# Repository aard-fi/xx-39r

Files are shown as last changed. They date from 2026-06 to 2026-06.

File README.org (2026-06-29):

* XX-39R                                                              :TOC_4:
- [[#overview][Overview]]
- [[#licensing][Licensing]]
- [[#quick-springtide-40-conversion-guide][Quick springtide 40 conversion guide]]
- [[#xx-39r265c27-3-the-original-hardware][XX-39R/265C27-3, the original hardware]]
- [[#elrs-replacement][ELRS replacement]]
  - [[#firmware][Firmware]]
    - [[#variants][Variants]]
    - [[#building][Building]]
    - [[#flashing][Flashing]]
    - [[#fuses][Fuses]]
  - [[#verify-functionality][Verify functionality]]

* Overview

This repository is for documenting a pretty bad receiver and motor driver board for a RC boat labeled =XX-39R= and =265C27-3=, as well as a replacement for it. The board can be found in models like "Revell Spring Tide 40", but has no place in a toy from this decade (or the last) - the reception is absolutely horrible, and there are better options available nowadays.

Read the sections below for a more detailed board description, as well as our "absolute overkill" option for replacing it with something better. While the replacement board is designed as drop in replacement for this model it has been designed with reusability for other small models in mind as well - which also would be listed here.

* Licensing

All source code is licensed under [[https://www.google.com/url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][GPLv2]]. PCB related KiCad files are licensed under [[https://creativecommons.org/licenses/by-nc-sa/4.0/][CC BY-NC-SA 4.0]].

* Quick springtide 40 conversion guide

Open all the screws on the boat, and open the small electronics box. Submerge the board into isopropyl alcohol for roughly 24 hours - and while wet, remove the plugs. They should come out relatively easy now.
Remove the antenna wire from the hole, and remove the board.

Assuming you have a board populated with SMD components, now you'll need to

- solder JST-PH 2.0 headers into J1, J2, J3 and J4
- solder a jumper into or bridge J13
- solder a pin header (male or female - female might be more comfortabe with some programmers) into J5
- solder a pin header into J6. Recommendation would be angled male, and female on the ELRS receiver

The layout is the same as the original - the JST headers and the ELRS module most go to the underside of the board (inside the silk screen markings). For the programmer an angled header has space on top as well, and can allow for easier reflashing.

Next you can connect your UPDI programmer to the board and the PC, download the latest firmware archive from the release page, unzip, and run =flash.sh= (Linux/MacOS) or =flash.ps1= (Windows), and follow the instructions. Select the 10MHz springtide firmware, and decide if you want the water sensor.

Plug in the ELRS receiver and he motor, battery and sensor wires. Do a quick functionality test with batteries and a remote and then put everything together.

* XX-39R/265C27-3, the original hardware

The board is built around the [[https://www.talkingelectronics.com/projects/27MHz%20Transmitters/imagesP2/RX2Bdatasheet-5function.pdf][TX-2B/RX-2B]] transmitter/receiver combo. The problem here is less with that chip, but more that it can be used with the cheapest possible receiver circuit (in this case, tuned to 40MHz), which does not behave well in the real world.

The remote control has 4 buttons: binary inputs for reverse/forward for each of the motors. So no speed control, and steering by only using one motor (or reversing the other, for tight turns).

The motor controller is a [[https://www.lcsc.com/product-detail/Motor-Driver-ICs_Mixic-MX1616H_C5119044.html][MX1616H]] - which is a reasonable choice for a boat powered by 4.5V.

Additionally, there's a protection circuit to detect a current between the two motors to avoid activation outside of the water.

The schematic in the =pcb= directory currently should be mostly complete, with the exception of the receiver circuit.

* ELRS replacement

For our replacement we're relying on an ELRS receiver. While absolute overkill for such a boat it'll allow a nice upgrade path to larger models later on. The hardware can support any small receivers using a serial protocol - so if you have spare older receivers around it can be adapted to use that instead. We don't want to touch other parts of the boat - so while we could use 14500 cells instead of AA we'd have to lower the voltage to make sure we don't burn out the motors.

The easier way is to just stick with the 4.5V architecture, and only boost voltage for the ELRS receiver.

We can reuse the motor controller as well as the protection circuit - but as we want to support the cheapest possible ELRS remotes we can't rely on track mixing in the remote, and therefore need a cheap microcontroller to interface between the receiver and the motor controller. We can use an AtTiny414 for that - it'll work over the complete voltage range we can expect this to operate at. An AtTiny412 would be possible - but we'd have to reuse the UPDI pin.

All unused pins on the MCU are lead out, as well as some spare footprints for VCC and GND pins. The complete table of pin headers is:

| Reference | Description     | Comment                                                                |
|-----------+-----------------+------------------------------------------------------------------------|
| J1        | Sense           |                                                                        |
| J2        | Battery         | Designed for 4.5V, but can take up to 5.5V                             |
| J3        | Port motor      |                                                                        |
| J4        | Starboard motor |                                                                        |
| J5        | UPDI            |                                                                        |
| J6        | Receiver        | Designed for ELRS, but can be used otherwise as well. See pinout below |
| J7        | PA6             |                                                                        |
| J8        | PA1             |                                                                        |
| J9        | PA3             |                                                                        |
| J10       | PA2             |                                                                        |
| J11       | Spare VCC       |                                                                        |
| J12       | Spare VCC       |                                                                        |
| J13       | Receiver VCC    | Bridge to use the on board booster, or connect your own                |
| J14       | Spare GND       |                                                                        |
| J15       | Spare GND       |                                                                        |
| J16       | Spare GND       |                                                                        |

The header for the (ELRS) receiver (=J6=) has the following pinout:

| Pin | ELRS | MCU           | Pin |
|-----+------+---------------+-----|
|   1 | GND  | GND           |     |
|   2 | VCC  | -             |     |
|   3 | TX   | PB3, UART1 RX |   6 |
|   4 | RX   | PB2, UART1 TX |   7 |

Any receiver using a serial protocol (like FlySky AFHDS) could be used, though the firmware here only supports ELRS.

The motor headers are connected as follows:

|           |          |       |      |     |          |
|-----------+----------+-------+------+-----+----------|
| Port      | J3 pin 1 | OUTA1 | INA1 | PA4 | =M1_FWD=   |
|           | J3 pin 2 | OUTB1 | INB1 | PA5 | =M1_REV=   |
| Starboard | J4 pin 1 | OUTA2 | INA2 | PB0 | =M2_FWD=   |
|           | J4 pin 2 | OUTB2 | INB2 | PB1 | =M2_REV= |

** Firmware

This is build with =common.hpp= containing code for all bigger features, and the individual firmware variants can use that to build model specific variants in less than 50 lines of code.

Common features are

- direction-change dead time (~50–80 ms coast) prevents regenerative voltage spikes
- rate limiting (±25 PWM per packet accel) makes it both more controllable (kid friendly) and prevents hardware destroying voltage spikes
- low-voltage cutoff (2.8 V) can stop motors before brownout
- custom CRSF parser, somewhat resilient: we try to re-sync if we read too much garbage, and stop the motors if we can't get it back
- water sensor readings, in safety mode (motors directly shut off) or just reading for extra data
- battery voltage readings
- support for different CPU speeds: 5, 10, 16 and 20MHz
- simple RX and TX buffering for UART communications
- optional "kickstart" support: on slow speeds do occasional kicks to get the motor started

*** Variants

We can build variants with extra features from base sources, with the filename containing markers to show what it is:

- *-ks* — Motor kickstart enabled (helps low-speed startup)
- *-ws* — Water safety sensor enabled. Recommended for kids - motors stop when the boat is removed from the water.
- *-5m*, *-10m*, *-16m* — CPU frequency variants (default = 20 MHz)

All release builds have frequency markers, only manual builds for development targets come without that, in which case 20MHz is assumed.

When running a model from batteries you generally should be using the 10MHz variant - that should be stable until relatively low voltages still. See fuse settings below if you want to push it even further by utilising brownout detection.

*** Building

Building only requires [[https://gcc.gnu.org/wiki/avr-gcc][avr-gcc]], and avr-libc in a variant new enough to have headers compatible with AtTiny414. On any sensible Linux distribution just installing those via the package manager should be fine, if you're using Ubuntu you can get a recent enough binary tarball via [[https://github.com/modm-io/avr-gcc][modm-io]].

On MacOS via homebrew you could do =brew tap osx-cross/avr && brew install avr-gcc@15=. Make sure it's in your path - either add it, or force linking it.

=make all-freqs= builds all variants.  Individual targets work too:

=make build/firmware-test-10m.hex= builds a single suffixed hex for 10 MHz.

=make FREQ=10m MOTOR_STALL_SPEED=120 all= customises stall speed before building.

*** Flashing

Flashing requires avrdude, as well as some UPDI programmer. Something like the [[https://www.adafruit.com/product/5879][UPDI friend]] is recommended, though you can [[https://github.com/ElTangas/jtag2updi][use some old Arduino]] as well.

When building from source =make flash= can be used - it will try to write =firmware.hex= to a UPDI programmer at =/dev/ttyUSB1=. You can override the firmware to flash with the =TARGET= variable, and the serial port with =PORT=: =make flash TARGET=firmware-test-pwm-starboard TARGET=/dev/ttyUSB0= would write the starboard motor test firmware via =ttyUSB0=.

Directly with avrdude the command for that would be =avrdude -c serialupdi -p t414 -U flash:w:firmware-test-pwm-starboard.hex:i -P /dev/ttyUSB0=

If you downloaded a release with prebuilt hex files, use the interactive scripts in =scripts/=:

- macOS / Linux: =./scripts/flash.sh=
- Windows: =powershell -ExecutionPolicy Bypass -File .\scripts\flash.ps1=

These scripts auto-detect your programmer, show current fuse values in plain English, and guide you through firmware selection.

*** Fuses

There are two fuses interesting for us:

- *BODCFG = 0x0A* — Brown-out detection enabled at 2.6 V
- *OSCCFG = 0x02* — 20 MHz internal oscillator

OSCCFG only needs to be set when running at 16MHz.

BODCFG configures the brownout detector, which can be useful to ensure the system gets back into a defined state when playing close to voltage limits.

Set with avrdude, or the included flash scripts.

** Verify functionality

This repository contains various specialised firmware bits to help debugging.

If the serial port is not working:

- flash =firmware-test-pb2= and check for a square wave on the =TX= pin of the ELRS header, and move on to =PB2= (pin 7) if there is none. This will either verify that the pin can be used - or point towards a hardware issue
- if the square wave test worked flash =firmware-test-uart= - this should be visible on the oscilloscope with the same settings, and a connected serial adapter should start printing =U=

For testing the motors:

- flash =firmware-test-gpio=. This will print to the serial port what it is testing, and will bitbang each motor port. Connected motors should spin up (in both directions), and this should be visible on a multimeter or oscilloscope
- flash =firmware-test-port= or =firmware-test-starboard= - those will cycle the port/starboard motor through reverse and forward PWM. If both spin correctly in both directions the motors are fine

For testing the water sensing:

- flash =firmware-test-water= and bridge J1, either with finger/metal or by sticking cables into water. It'll dump readings via serial

With all of the above sorted out you can flash =firmware-test= for a simple interactive serial interface to control all of the above. It'll spam a banner to serial until it receives a first keypress.

Steering should be channel 1 idle 0, -100 to 100. throttle should be channel 3, idle -100, up to 100.

Channels 5 and 8 may be used as toggle switches, channels 6 and 7 as tristate switches.

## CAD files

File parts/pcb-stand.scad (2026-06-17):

$fn = 60;

pcb_width = 36; // adjust depending on manufacturing tolerances for the PCB
pcb_thickness = 1.8;
component_clearance = 1.2; // adjust if that hits components

wall_thickness = 3.0; // thickness of the plastic walls of the groove
slot_depth = 15.0;    // how high up the sides the U-profile grips
base_height = 5.0;    // thickness of the bottom mounting plate
base_extension = 12.0; // how far the base extends out for screws

// screw holes (for standard wood screws)
screw_shanks_dia = 4.0; // diameter of the screw thread
screw_head_dia = 8.0;  // diameter of the recessed screw head
screw_head_depth = 3.0; // how deep the countersink goes

// total width of the plastic tower block before cutting the grooves and middle out
total_width = pcb_width + (2 * wall_thickness);
total_depth = pcb_thickness + (2 * wall_thickness);
total_length = total_width + (2 * base_extension);

difference() {
    union() {
        // base plate for screwing into wood
        cube([total_length, total_depth, base_height]);

        // vertical block across the center (will be hollowed out into towers)
        translate([base_extension, 0, base_height])
            cube([total_width, total_depth, slot_depth]);
    }

    // the pcb slot (cuts the groove depth into the towers)
    // positioned so the PCB edges sit exactly at the right width apart
    translate([base_extension + wall_thickness, wall_thickness, base_height])
        cube([pcb_width, pcb_thickness, slot_depth + 1]);

    // the middle clearance cutout
    // this removes the entire middle section to clear components,
    // leaving behind two towers with inward-facing U-grooves.
    translate([base_extension + wall_thickness + component_clearance, -1, base_height])
        cube([pcb_width - (2 * component_clearance), total_depth + 2, slot_depth + 1]);

    // left screw hole (countersunk)
    translate([base_extension / 2, total_depth / 2, -0.5]) {
        cylinder(d = screw_shanks_dia, h = base_height + 1);
        translate([0, 0, base_height - screw_head_depth + 0.5])
            cylinder(d1 = screw_shanks_dia, d2 = screw_head_dia, h = screw_head_depth);
    }

    // right screw hole (countersunk)
    translate([total_length - (base_extension / 2), total_depth / 2, -0.5]) {
        cylinder(d = screw_shanks_dia, h = base_height + 1);
        translate([0, 0, base_height - screw_head_depth + 0.5])
            cylinder(d1 = screw_shanks_dia, d2 = screw_head_dia, h = screw_head_depth);
    }
}

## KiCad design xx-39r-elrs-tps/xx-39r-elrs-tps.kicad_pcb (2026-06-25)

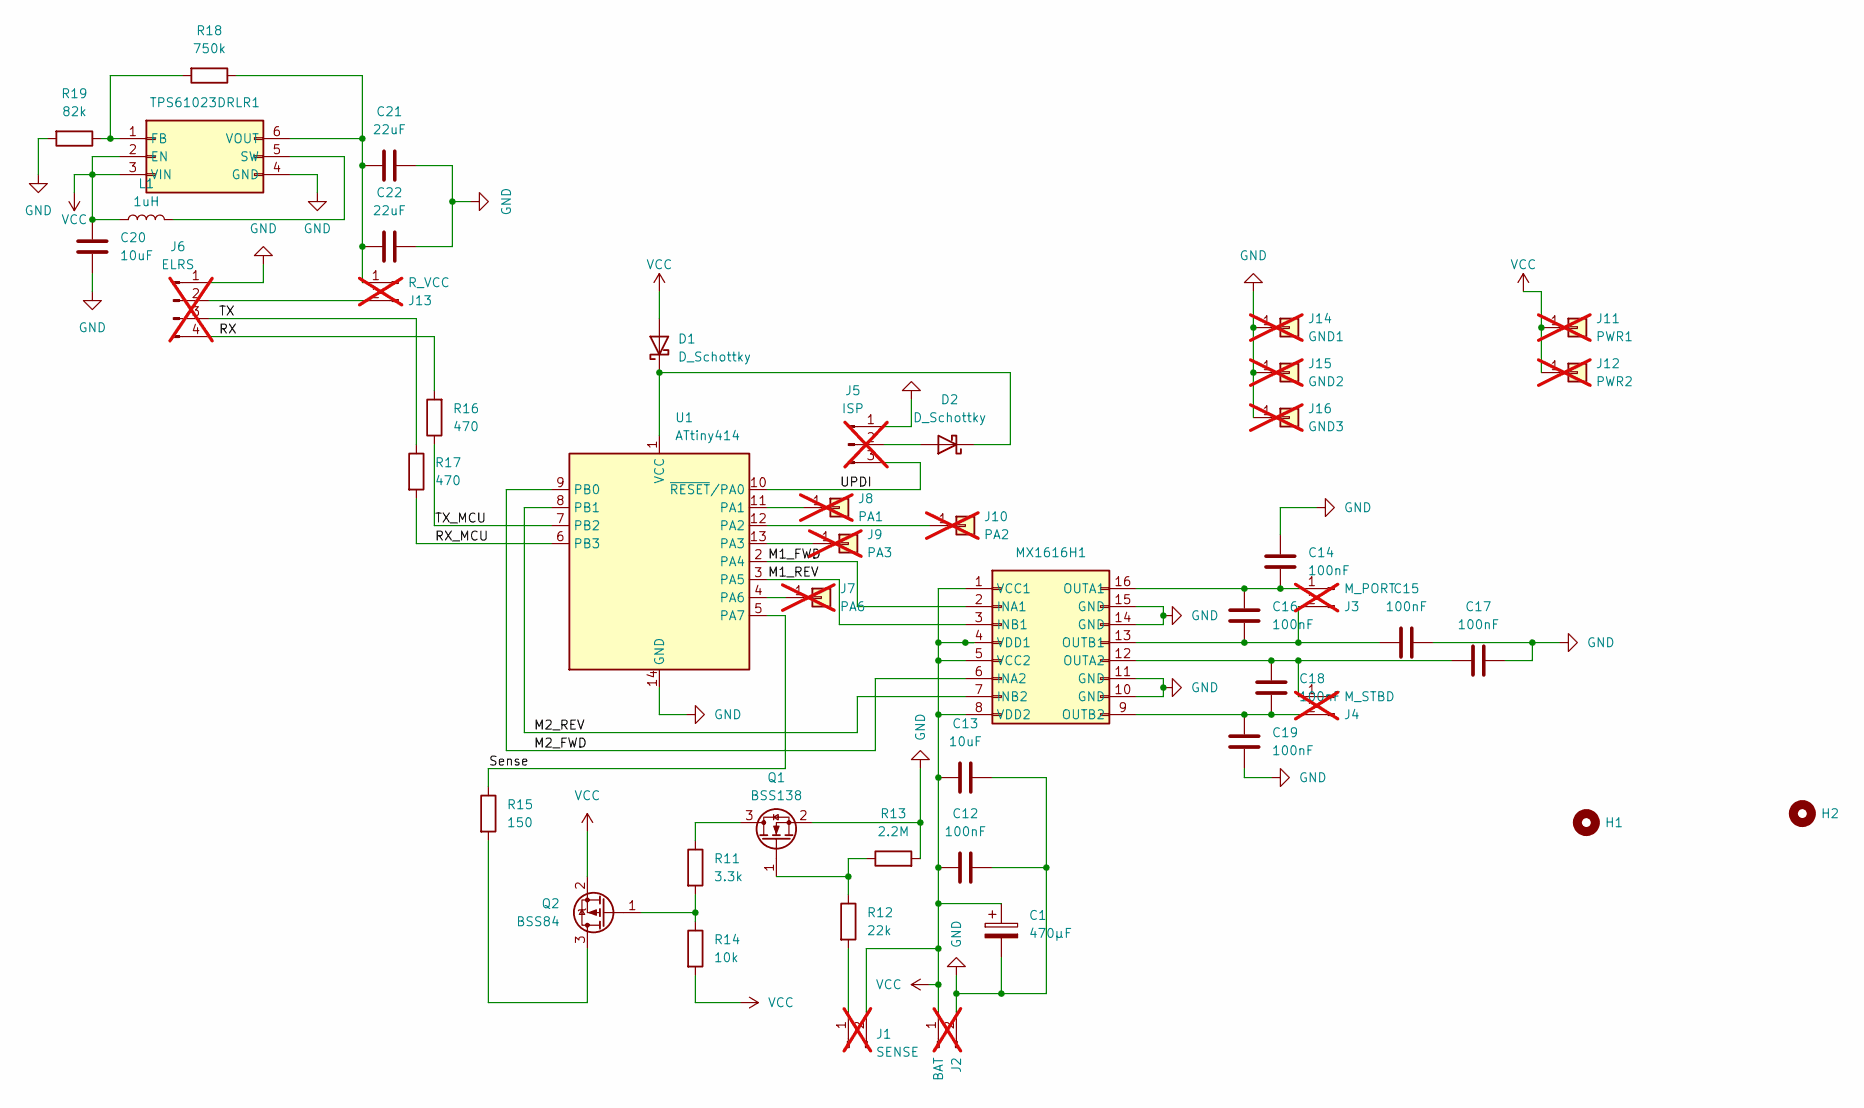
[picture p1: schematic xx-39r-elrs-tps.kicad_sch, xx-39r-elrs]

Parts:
C1: 470µF; CP_Elec_6.3x5.4; LCSC C7469933
C12, C14, C15, C16, C17, C18, C19: 100nF; C_0402_1005Metric
C13, C20: 10uF; C_0603_1608Metric
C21, C22: 22uF; C_0805_2012Metric
D1, D2: D_Schottky; D_SOD-123; LCSC C7370889
H1, H2: MountingHole_3mm
J1: SENSE; JST_PH_S2B-PH-K_1x02_P2.00mm_Horizontal; not fitted
J2: BAT; JST_PH_S2B-PH-K_1x02_P2.00mm_Horizontal; not fitted
J3: M_PORT; JST_PH_S2B-PH-K_1x02_P2.00mm_Horizontal; not fitted
J4: M_STBD; JST_PH_S2B-PH-K_1x02_P2.00mm_Horizontal; not fitted
J5: ISP; PinHeader_1x03_P2.54mm_Vertical; not fitted
J6: ELRS; PinHeader_1x04_P2.54mm_Vertical; not fitted
J7: PA6; PinHeader_1x01_P2.54mm_Vertical; not fitted
J8: PA1; PinHeader_1x01_P2.54mm_Vertical; not fitted
J9: PA3; PinHeader_1x01_P2.54mm_Vertical; not fitted
J10: PA2; PinHeader_1x01_P2.54mm_Vertical; not fitted
J11: PWR1; PinHeader_1x01_P2.54mm_Vertical; not fitted
J12: PWR2; PinHeader_1x01_P2.54mm_Vertical; not fitted
J13: R_VCC; PinHeader_1x02_P2.54mm_Vertical; not fitted
J14: GND1; PinHeader_1x01_P2.54mm_Vertical; not fitted
J15: GND2; PinHeader_1x01_P2.54mm_Vertical; not fitted
J16: GND3; PinHeader_1x01_P2.54mm_Vertical; not fitted
L1: 1uH; L_1008_2520Metric; LCSC C286537
MX1616H1: SOIC-16_3.9x9.9mm_P1.27mm; LCSC C5119044
Q1: BSS138; SOT-23; LCSC C7420339
Q2: BSS84; SOT-23; LCSC C114481
R11: 3.3k; R_0603_1608Metric
R12: 22k; R_0603_1608Metric
R13: 2.2M; R_0603_1608Metric
R14: 10k; R_0603_1608Metric
R15: 150; R_0603_1608Metric
R16, R17: 470; R_0603_1608Metric
R18: 750k; R_0603_1608Metric
R19: 82k; R_0603_1608Metric
TPS61023DRLR1: SOT-563; LCSC C919459
U1: ATtiny414; SOIC-14_3.9x8.7mm_P1.27mm; LCSC C189365

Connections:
/M1_FWD: MX1616H1.2 (INA1), U1.2 (PA4)
/M1_REV: MX1616H1.3 (INB1), U1.3 (PA5)
/M2_FWD: MX1616H1.6 (INA2), U1.9 (PB0)
/M2_REV: MX1616H1.7 (INB2), U1.8 (PB1)
/RX: J6.4, R16.2
/RX_MCU: R17.2, U1.6 (PB3)
/Sense: R15.1, U1.5 (PA7)
/TX: J6.3, R17.1
/TX_MCU: R16.1, U1.7 (PB2)
/UPDI: J5.3, U1.10 (~RESET/PA0)
GND: C1.2, C12.2, C13.2, C14.1, C15.2, C17.2, C19.2, C20.1, C21.1, C22.1, J2.2, J5.1, J6.1, J14.1 (Pin_1_1), J15.1 (Pin_1_1), J16.1 (Pin_1_1), MX1616H1.10 (GND), MX1616H1.11 (GND), MX1616H1.14 (GND), MX1616H1.15 (GND), Q1.2 (S), R13.2, R19.2, TPS61023DRLR1.4 (GND), U1.14 (GND)
unnamed: D1.1 (K), D2.1 (K), U1.1 (VCC)
unnamed: D2.2 (A), J5.2
unnamed: J1.1, R12.2
unnamed: C14.2, C16.1, J3.1, MX1616H1.16 (OUTA1)
unnamed: C15.1, C16.2, J3.2, MX1616H1.13 (OUTB1)
unnamed: C17.1, C18.1, J4.1, MX1616H1.12 (OUTA2)
unnamed: C18.2, C19.1, J4.2, MX1616H1.9 (OUTB2)
unnamed: J7.1 (Pin_1_1), U1.4 (PA6)
unnamed: J8.1 (Pin_1_1), U1.11 (PA1)
unnamed: J9.1 (Pin_1_1), U1.13 (PA3)
unnamed: J10.1 (Pin_1_1), U1.12 (PA2)
unnamed: C21.2, C22.2, J13.1, R18.1, TPS61023DRLR1.6 (VOUT)
unnamed: J6.2, J13.2
unnamed: Q1.3 (D), R11.1
unnamed: Q1.1 (G), R12.1, R13.1
unnamed: Q2.3 (D), R15.2
unnamed: Q2.1 (G), R11.2, R14.1
unnamed: R18.2, R19.1, TPS61023DRLR1.1 (FB)
unnamed: L1.2, TPS61023DRLR1.5 (SW)
VCC: C1.1, C12.1, C13.1, C20.2, D1.2 (A), J1.2, J2.1, J11.1 (Pin_1_1), J12.1 (Pin_1_1), L1.1, MX1616H1.1 (VCC1), MX1616H1.4 (VDD1), MX1616H1.5 (VCC2), MX1616H1.8 (VDD2), Q2.2 (S), R14.2, TPS61023DRLR1.2 (EN), TPS61023DRLR1.3 (VIN)

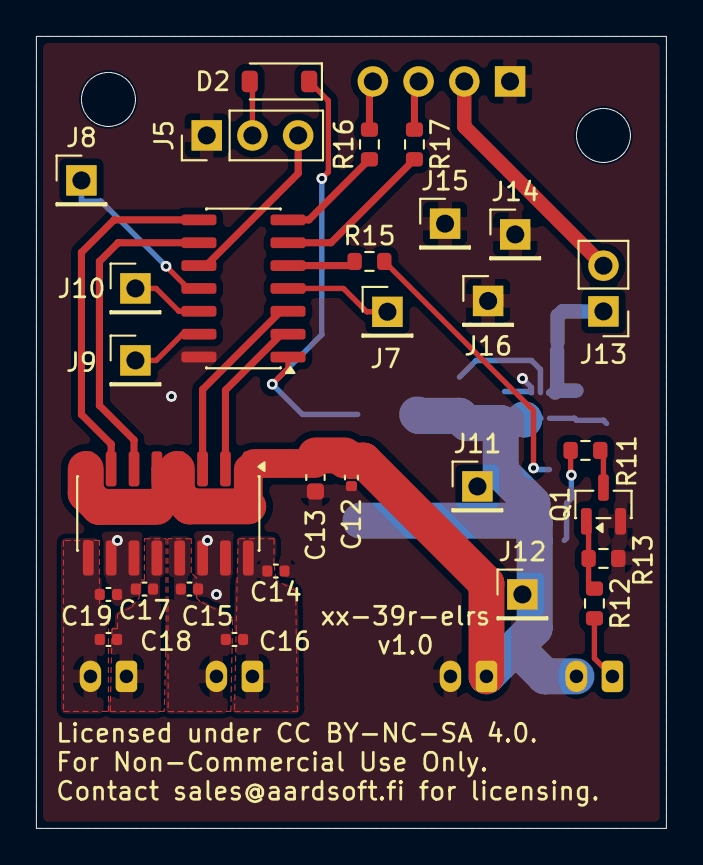
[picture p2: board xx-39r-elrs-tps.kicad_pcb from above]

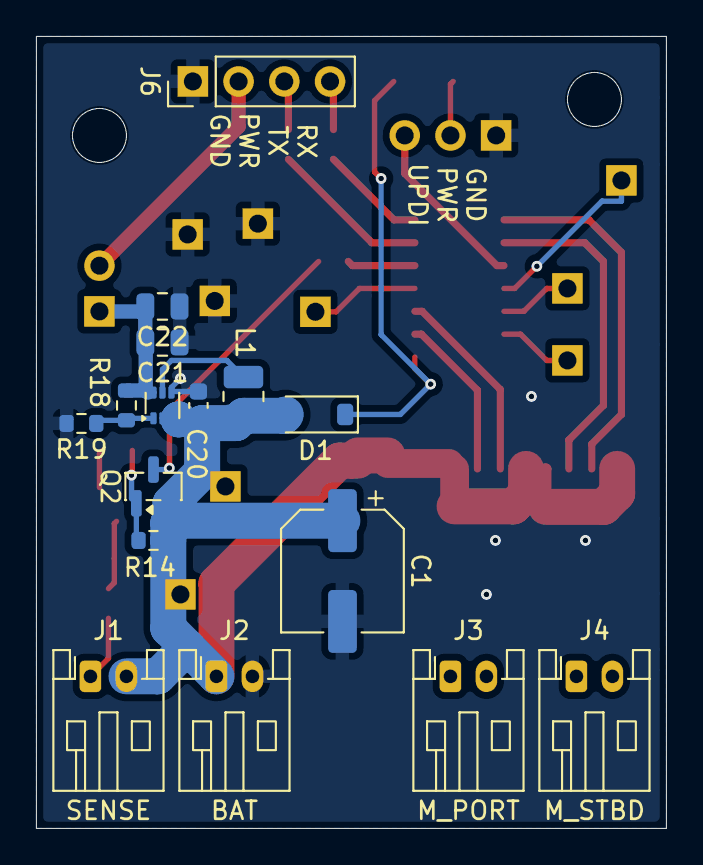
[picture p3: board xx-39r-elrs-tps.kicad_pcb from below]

Board: 2 copper layers, 35.0 x 44.0 mm, 47 parts (16 on the bottom side), 31 nets.

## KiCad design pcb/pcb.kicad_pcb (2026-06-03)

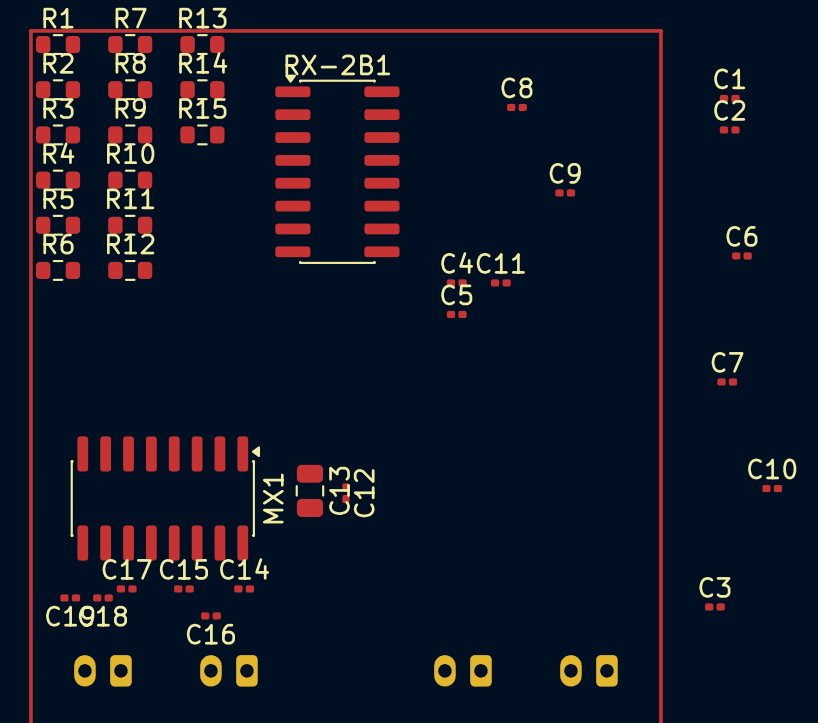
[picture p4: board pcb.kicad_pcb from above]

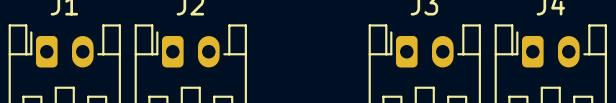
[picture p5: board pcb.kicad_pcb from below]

Board: 2 copper layers, 40 parts (4 on the bottom side), 10 nets, no tracks yet.

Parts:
C1, C2, C3, C4, C5, C6, C7, C8, C9, C10, C11, C12, C14, C15, C16, C17, C18, C19: 100nF; C_0201_0603Metric
C13: 10uF; C_0805_2012Metric
J1: SENSE; JST_PH_S2B-PH-K_1x02_P2.00mm_Horizontal
J2: BAT; JST_PH_S2B-PH-K_1x02_P2.00mm_Horizontal
J3: M_PORT; JST_PH_S2B-PH-K_1x02_P2.00mm_Horizontal
J4: M_STBD; JST_PH_S2B-PH-K_1x02_P2.00mm_Horizontal
MX1: SOIC-16_3.9x9.9mm_P1.27mm
R1, R2, R3, R4, R5, R6, R7, R8, R9, R10, R11, R12, R13, R14, R15: R; R_0603_1608Metric
RX-2B1: SOIC-16_3.9x9.9mm_P1.27mm

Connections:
GND: C12.2, C13.2, C14.1, C15.2, C17.2, C19.2, J2.2, MX1.10 (GND), MX1.11 (GND), MX1.14 (GND), MX1.15 (GND)
unnamed: C12.1, C13.1, J2.1, MX1.1 (VCC1), MX1.4 (VDD1), MX1.5 (VCC2), MX1.8 (VDD2)
unnamed: C14.2, C16.1, J3.1, MX1.16 (OUTA1)
unnamed: C15.1, C16.2, J3.2, MX1.13 (OUTB1)
unnamed: C17.1, C18.1, J4.1, MX1.12 (OUTA2)
unnamed: C18.2, C19.1, J4.2, MX1.9 (OUTB2)
unnamed: MX1.2 (INA1), RX-2B1.11 (FORWARD)
unnamed: MX1.6 (INA2), RX-2B1.7 (LEFT)
unnamed: MX1.3 (INB1), RX-2B1.10 (BACKWARD)
unnamed: MX1.7 (INB2), RX-2B1.6 (RIGHT)

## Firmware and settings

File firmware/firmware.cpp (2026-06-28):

/**
 * @file firmware.cpp
 * @copyright Copyright (c) 2026 Bernd Wachter
 * @author Bernd Wachter <bernd-github@wachter.fi>
 * @date 2026
 *
 * ELRS receiver -> motor driver bridge for XX-39R replacement board.
 *
 * See common.hpp or README.org for wiring details.
 */

#include <avr/version.h>

#include "common.hpp"

void mixMotors(uint16_t steer, uint16_t thr);

// NOTE: the CRSF part is not properly tested yet - the rest should be fine
int main() {
  wdt_disable();

  bootstrap();
  initPWM();
  stopAll();

  while (1) {
    wdt_reset();

#if WATER_SAFETY_MODE == 0
    if (!water_detected) {
      stopAll();
      continue;
    }
#else
    if (water_detected) {
      stopAll();
      continue;
    }
#endif

    // Low-voltage cutoff: if battery_data is available and below threshold,
    // stop everything and wait for voltage recovery.
#if LOW_VOLTAGE_CUTOFF_MV > 0
    if (battery_data && battery_data < LOW_VOLTAGE_CUTOFF_MV) {
      stopAll();
      continue;
    }
#endif

    // look for standard 26-byte CRSF frame
    if (uartAvailable() >= 26) {
      if (uartRead() == 0xC8) {     // CRSF address
        if (uartRead() == 24) {   // frame length
          if (uartRead() == 0x16) { // channels type packet

            uint8_t packet[22];
            for (uint8_t i = 0; i < 22; i++) {
              packet[i] = uartRead();
            }
            uint8_t crc = uartRead(); // CRC byte

            uint8_t crc_buf[24];
            crc_buf[0] = 24;
            crc_buf[1] = 0x16;
            for (uint8_t i = 0; i < 22; i++) crc_buf[i + 2] = packet[i];
            if (crc == crsfCRC8(crc_buf, 24)) {
              // extract steering (Ch3) and throttle (Ch1)
              uint16_t steering = ((packet[4] >> 1) | (packet[5] << 7)) & 0x07FF;
              uint16_t throttle = ((packet[1] >> 3) | (packet[2] << 5)) & 0x07FF;
              mixMotors(steering, throttle);
            }
            // CRC mismatch: silently drop the frame
          }
        }
      }
    }
  }
  return 0;
}

void mixMotors(uint16_t steer, uint16_t thr) {
  int16_t forwardSpeed = mapValue(thr, 172, 1811, -255, 255);
  int16_t steeringBias = mapValue(steer, 172, 1811, -255, 255);

  int16_t portMotor = forwardSpeed + steeringBias;
  int16_t starboardMotor = forwardSpeed - steeringBias;

  setMotorPort(prepareMotorSpeed(portMotor));
  setMotorStarboard(prepareMotorSpeed(starboardMotor));
}

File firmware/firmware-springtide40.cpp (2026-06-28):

/**
 * @file firmware-springtide40.cpp
 * @copyright Copyright (c) 2026 Bernd Wachter
 * @author Bernd Wachter <bernd-github@wachter.fi>
 * @date 2026
 *
 * ELRS receiver -> motor driver bridge for XX-39R replacement board.
 *
 * See common.hpp or README.org for wiring details.
 *
 * This variants specifically targets the Revell Spring Tide 40,
 * trying to make it as nicely playable as possible.
 * https://revell.com/en-eu/products/241369090-speedboat-dolphin
 */

#include <avr/version.h>

// boat-specific motor tuning: these 130-size motors need ~140 on the 0-255
// scale (~55% duty with PWM_MAX=160) to reliably start from idle. Needs some
// proper testing and fine tuning in water still.
#define MOTOR_STALL_SPEED 140

#define WATER_SAFETY_MODE 0
#include "common.hpp"

void mixMotors(uint16_t steer, uint16_t thr);

// NOTE: the CRSF part is not properly tested yet - the rest should be fine
int main() {
  wdt_disable();

  bootstrap();
  initPWM();
  stopAll();

  // if running on battery and motors go full-throttle then freeze,
  // check supply voltage under load. 20 MHz requires VCC >= 4.5V per
  // datasheet; sag below that causes clock instability. When running from
  // batteries this only is supported with the 10MHz binary.

  while (1) {
    wdt_reset();

#ifdef WATER_SENSOR
    if (!water_detected) {
      stopAll();
      continue;
    }
#endif

    // low-voltage cutoff: if battery measurement is below threshold, stop
    // everything.  This protects the regulator and motors from brownout.
#if LOW_VOLTAGE_CUTOFF_MV > 0
    if (battery_data && battery_data < LOW_VOLTAGE_CUTOFF_MV) {
      stopAll();
      continue;
    }
#endif

    processCrsfBuffer();

    // failsafe: stop motors if no valid CRSF packet for ~1 second
    static uint16_t failsafe_cnt = 0;
    if (rc_data.is_new_data) {
      rc_data.is_new_data = false;
      failsafe_cnt = 0;
      mixMotors(rc_data.steering, rc_data.throttle);
    } else if (++failsafe_cnt >= 10000) {
      failsafe_cnt = 10000;
      stopAll();
    }

    /*
     * handle toggle switches
     if (rc_data.aux1){
     }
    */
  }
  return 0;
}

void mixMotors(uint16_t steer, uint16_t thr) {
  int16_t forwardSpeed = mapValue(thr, 172, 1811, -255, 255);
  int16_t steeringBias = mapValue(steer, 172, 1811, -255, 255);

  int16_t portMotor = forwardSpeed + steeringBias;
  int16_t starboardMotor = forwardSpeed - steeringBias;

  setMotorPort(prepareMotorSpeed(portMotor));
  setMotorStarboard(prepareMotorSpeed(starboardMotor));
}

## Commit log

2026-06-03 Import initial stage of reverse engineering of XX-39R board
    Mainly the antenna section is missing now
    [pcb.kicad_pcb, pcb.kicad_sch]
2026-06-17 Add firmware, documentation and test bits
    [pcb-stand.scad]
2026-06-17 Add v1 pcb and related license information
    [xx-39r-elrs.kicad_pcb, xx-39r-elrs.kicad_sch]
2026-06-17 Add delay for ADC readings
    Original code worked by accident, presumably due to shared ground on
    the bench PSU. With a more isolated PSU things went wrong, until the
    delay got added. I really should start remembering that, can't recount
    how often I ran into that with Atmel CPUs.
    [common.hpp]
2026-06-17 Add comment about PWM frequency tests
2026-06-17 Add experimental support for kicking the motor on low speeds
    We'll eventually need to map out the range where the motors definitely
    don't work - but by kicking the min we might be able to increase the
    range a bit. This is intentionally a separate compile flag, and
    produces separate firmware files, as it may not end up being a good thing.
2026-06-22 Use 0805 for C21/C22
    The actual capacitance of the old 0402 might drop below TPS
    requirements under load.
    [xx-39r-elrs.kicad_pcb, xx-39r-elrs.kicad_sch]
2026-06-25 Add a separate copy of the board with integrated boost converter
    Tests have shown modern ELRS receivers _may_ be fine running directly
    off 3 AA cells, even with some voltage sagging, so we'll explore that
    in the default layout, and keep this for the integrated voltage
    booster.
    Moving the voltage booster off the default, and just providing a 3-pin
    header for plugging in an optional booster PCB has a few advantages:
    - we'll be able to move all SMD components to a single side, which
    takes complexity out of PCBA (and removes the setup fee for one side
    when using JLCPCB)
    - remaining components can be more easily handsoldered, especially if
    we bump the remaining capacitors to 0603. So offe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
    [xx-39r-elrs-tps.kicad_pcb, xx-39r-elrs-tps.kicad_sch]
2026-06-25 Change R19 to 100K
    With the 82K we were ending up with 5.8V boosted output, which made
    the TPS cook itself. This now lowers it to a safe 5.2V with what I
    have at hand (should be closer to 5V).
    [xx-39r-elrs-tps.kicad_sch]
2026-06-25 Add separate springtide40 firmware
    Target is firmware optimised for this specific hardware, while we can
    do a bit more experiments in the main firmware.
2026-06-27 Add 5/10/16MHz variants
    At 20MHz we'd need a stable 4.5V supply - which we can't guarantee on
    3 AA cells, and definitely won't have with nimh or 1S lipos. Best
    compromise is probably 10MHz (stable down to 2.7V), but to make it
    easy to switch this removes clock specific codes, and adds support for
    building the firmware in variants for 5/10/16 and 20MHz. 16MHz
    requires changing the fuse for selecting the oscillator.
    [common.hpp]
2026-06-27 Prepare custom PWM frequencies
    Motors seem to behave better at low speed at high frequencies, but
    lowering the clock reduces the default frequencies -> we raise them
    again, at the cost of resolution.
    This alters the maximum value we should be writing to PWM registers -
    so this commit alone introduces unwanted behaviour, as we're still
    using 255 everywhere. An upcoming commit will fix that by introducing
    normalisation of the 255 range into whatever PWM frequencies we have
    configured.
    [common.hpp]
2026-06-28 Add proper logic for CRSF, water sensor and battery reading
    - add a custom minimalistic CRSF implementation, copying all channels
    we might care about into a global struct
    - add timer driven water sensor and battery reading - with water
    sensor readings frequent enough that it can be used as safety device
    - implement protection functions in the main motor wrappers to prevent
    fast direction/speed changes. In extreme situations we may be able
    to generate more current from the motors than our minimal protection
    circuit can bleed off - to reduce the risk of hardware damage (and
    improve handling) we bring that down to safe limits.
    [common.hpp, firmware-test-water.cpp, firmware-test.cpp]
2026-06-28 Use shared (and improved) CRSF code for springtide model

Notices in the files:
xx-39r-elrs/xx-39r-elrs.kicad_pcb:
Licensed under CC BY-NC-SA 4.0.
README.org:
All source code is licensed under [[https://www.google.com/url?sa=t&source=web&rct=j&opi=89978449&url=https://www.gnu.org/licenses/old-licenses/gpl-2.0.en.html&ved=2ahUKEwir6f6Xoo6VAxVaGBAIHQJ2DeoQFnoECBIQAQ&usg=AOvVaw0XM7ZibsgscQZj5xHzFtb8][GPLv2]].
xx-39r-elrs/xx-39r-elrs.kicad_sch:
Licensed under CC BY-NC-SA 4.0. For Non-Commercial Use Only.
